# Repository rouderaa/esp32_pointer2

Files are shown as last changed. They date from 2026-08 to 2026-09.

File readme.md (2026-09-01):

# Virtual blind walking stick

This sketch turns a Benewake TFMini-S / TFMini-Plus lidar rangefinder into a parking-sensor-style audible proximity alert, streamed wirelessly to a Bluetooth A2DP speaker instead of a wired buzzer. Beep rate increases as the sensed object gets closer, and pitch steps up by an octave every 4 m of range.
The idea is that a visual impaired person can use this to navigate the environment simular to using a walking stick. The advantage of this electronic version is that the range is much larger, up to 12 metre and no toughing of the object is necessary. So for example a glass window can be measured instead of using a stick to tap it.

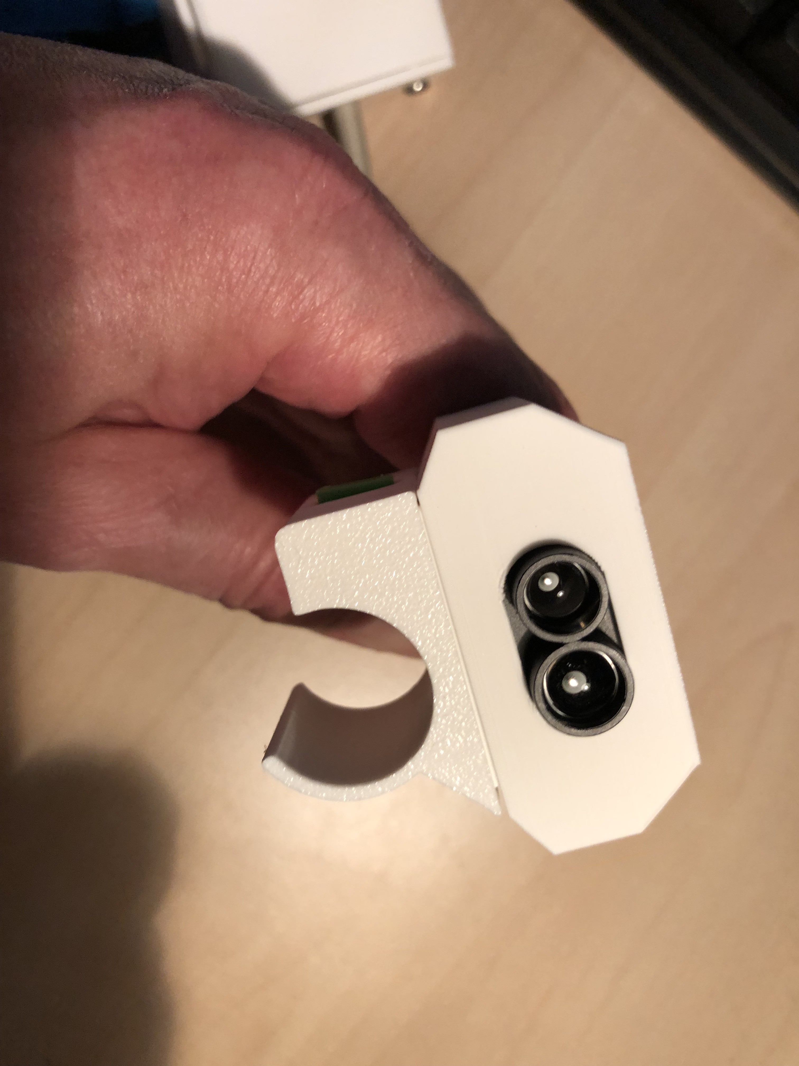
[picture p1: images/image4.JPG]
distance sensor part


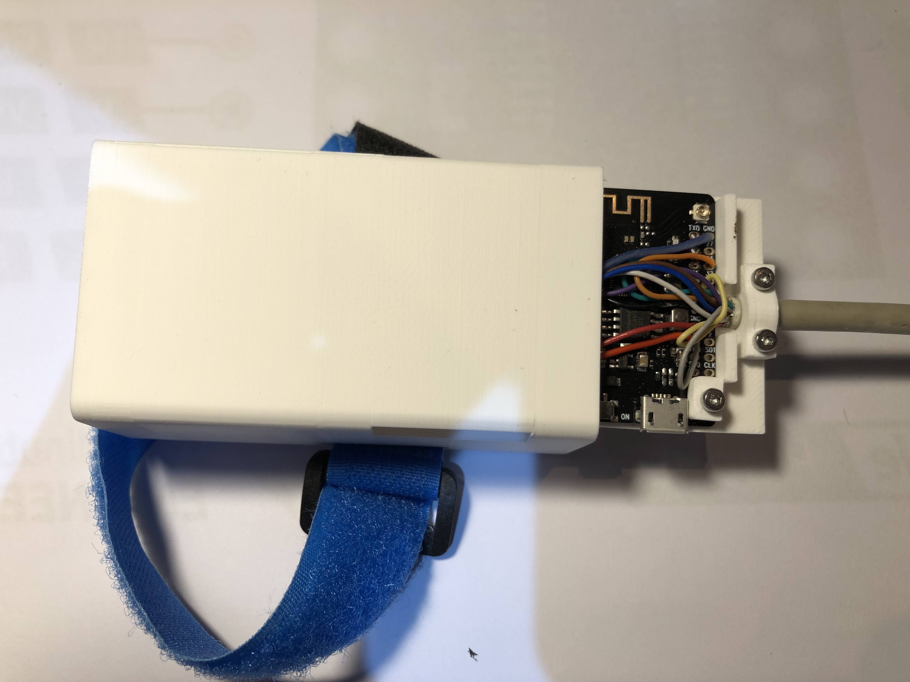
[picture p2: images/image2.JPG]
control box part


## How it works

1. **Sensing** — A TFMini-S lidar module is read over UART (ESP32 `HardwareSerial` UART1) via the `TFMPlus` driver library, reporting distance in cm at up to 100 Hz.
2. **Mapping distance → sound**
   - **Beep rate**: distance is linearly mapped from `DIST_MIN_MM`–`DIST_MAX_MM` (10 cm–12 m) to an inter-beep delay of `BEEP_DELAY_MIN_MS`–`BEEP_DELAY_MAX_MS` (80–800 ms), so closer objects beep faster.
   - **Pitch**: range is split into 4 m-wide octave bands. The farthest band plays at `BASE_FREQUENCY_HZ` (220 Hz); each band closer than that doubles the frequency, so the nearest band plays four octave-steps higher.
   - Both are recomputed continuously (non-blocking sequencer), so a sudden distance change is reflected within one `loop()` iteration (~10 ms) rather than waiting out a stale timing window.
3. **Sound synthesis** — Tones are generated in software as a small additive sine synthesis (fundamental + 4 harmonics) inside the Bluetooth audio callback (`get_sound_data`), with a short envelope ramp on beep/mute transitions to avoid audible clicks.
4. **Output** — Audio is streamed over Bluetooth A2DP (`ESP32-A2DP` library) to a paired speaker/receiver named `"B66"`, with auto-reconnect enabled.
5. **Controls**
   - A physical button (`PIN_KEY`, active-low, debounced) toggles mute; an LED (`PIN_LED`) reflects the current mute state.
   - Volume can be adjusted at runtime by sending `+` / `-` characters over the Serial console (steps of 5, clamped 0–127).

## Hardware

| Signal | ESP32 Pin | Notes |
|---|---|---|
| LED (mute indicator) | GPIO 22 | Active-high |
| Mute button | GPIO 23 | `INPUT_PULLUP`, active-low |
| Lidar RX (ESP32 RX) | GPIO 18 | TFMini-S TX → ESP32 RX |
| Lidar TX (ESP32 TX) | GPIO 21 | TFMini-S RX ← ESP32 TX |

The TFMini-S's signal pins are dual-purpose (UART RX/TX or I²C SDA/SCL). At boot, `ensureLidarUARTMode()` briefly opens the same two pins as I²C and unconditionally sends the sensor's "switch to UART mode" + "save settings" command bytes, in case a previous session left it in I²C mode. This is done unconditionally (not gated on an address probe) because a marginal I²C bus can make presence-detection unreliable. The pins are then released and reopened as UART. This step can be skipped by setting `SKIP_I2C_MODE_CHECK` to `1`.

## Configuration

Key tunables are grouped near the top of the source file:

- **Distance range**: `DIST_MIN_MM`, `DIST_MAX_MM` — sensor range mapped to sound (defaults: 10 cm–12 m, the TFMini-S's full rated range).
- **Beep timing**: `BEEP_DELAY_MIN_MS`, `BEEP_DELAY_MAX_MS`, `BEEP_ON_MS` — inter-beep gap range and fixed beep length.
- **Pitch**: `OCTAVE_BAND_MM`, `BASE_FREQUENCY_HZ` — width of each octave band and the base (farthest-band) frequency.
- **Volume**: `VOLUME_MIN`, `VOLUME_MAX`, `VOLUME_STEP` — runtime volume control bounds via Serial `+`/`-`.
- **Mute debounce**: `KEY_DEBOUNCE_MS`.
- **`DEBUG_SENSOR`** (0/1) — enables verbose Serial logging (raw sensor readings, a 1 Hz heartbeat, and a raw UART byte dump at boot). Off by default since each `Serial.printf()` costs ~1–2 ms and can add loop jitter.
- **`SKIP_I2C_MODE_CHECK`** (0/1) — skips the boot-time I²C mode-recovery step described above.

## Behavior notes

- If the sensor hasn't produced a new frame since the last `loop()` call, the last known-good distance is reused rather than treated as "out of range," so beeping stays smooth between UART frames.
- A reading is treated as invalid (and the beeper goes silent) when the TFMini-S reports a non-positive distance or a signal-strength ("flux") value below 100 — both indicate an unreliable measurement (target too close/far, low reflectivity, or ambient light saturation).
- The beep sequencer keeps running on its normal schedule even while muted; muting is applied downstream in the audio callback, so un-muting resumes in sync with the current distance instead of needing to "catch up."
- All audio-callback state (`toneState`, `muted`) is `volatile`, since it's written from `loop()` and read from the separate Bluetooth audio task.

## Dependencies

- [Arduino core for ESP32](https://github.com/espressif/arduino-esp32)
- [`TFMPlus`](https://github.com/budryerson/TFMini-Plus) — Benewake TFMini-Plus/TFMini-S UART driver
- [`ESP32-A2DP`](https://github.com/pschatzmann/ESP32-A2DP) (`BluetoothA2DPSource`)
- `Wire` (bundled with the ESP32 core)

## Usage

1. Wire the TFMini-S to the ESP32 as described above, plus the mute button and LED.
2. Install the dependencies listed above in your Arduino/PlatformIO environment.
3. Flash the sketch. On boot it will:
   - attempt to recover the lidar from I²C mode if needed,
   - verify UART communication with the sensor (halting with a Serial error if it fails),
   - set the sensor to continuous 100 Hz output,
   - start advertising/connecting as Bluetooth source `"B66"`.
4. Pair `"B66"` with your Bluetooth speaker/receiver (auto-reconnect is enabled for subsequent boots).
5. Open the Serial Monitor at 115200 baud to see status messages, and optionally send `+`/`-` to adjust volume.
6. Press the button on `PIN_KEY` to mute/unmute; the LED tracks mute state.

## Troubleshooting

- **"TFMini-S init failed — check wiring!"** at boot: the firmware-version handshake failed. Check power, and that RX/TX aren't swapped. Set `DEBUG_SENSOR` to `1` to see a raw 1-second UART byte dump at boot, which helps distinguish "nothing arriving" (power/baud/wiring) from "garbled data" (baud mismatch or swapped lines) from "sensor alive but command handshake failing."
- **No audio at all**: check the Serial log for A2DP connection-state messages (`a2dpConnectionStateChanged`) to confirm the Bluetooth link is actually established — audio silently doesn't play if it isn't. With `DEBUG_SENSOR` enabled, the 1 Hz heartbeat log also reports whether the beep sequencer is going active and whether A2DP reports connected.
- **Suspect the sensor is stuck in I²C mode**: leave `SKIP_I2C_MODE_CHECK` at `0` (default) so `ensureLidarUARTMode()` runs at boot; it will attempt to switch and save UART mode regardless of whether it can confirm the sensor's current state.# TTGO T7 v1.3 (ESP32) — PlatformIO Project

PlatformIO configuration for the **LilyGO TTGO T7 v1.3** (Mini32 / ESP32-WROVER-B), targeting Arduino framework projects that use LiDAR distance sensing (TFMini Plus) and Bluetooth A2DP audio.

## Hardware

- **Board:** LilyGO TTGO T7 v1.3 (Mini32)
- **Module:** ESP32-WROVER-B
- **PSRAM:** 4 MB
- **Flash:** 4 MB (default partition scheme, OTA-capable)

## Environment

| Setting | Value |
|---|---|
| Environment name | `ttgo-t7-v13` |
| Platform | `espressif32@6.3.2` |
| Board | `esp32dev` |
| Framework | `arduino` |

## Serial / Upload Settings

| Setting | Value |
|---|---|
| Monitor speed | `115200` |
| Monitor port | `/dev/ttyUSB2` |
| Upload speed | `921600` |
| Upload port | `/dev/ttyUSB2` |

> Adjust `monitor_port` / `upload_port` to match your system (e.g. `/dev/ttyUSB0`, `COM5`, etc.).

## Build Flags

- `-DBOARD_HAS_PSRAM` — enables the 4 MB PSRAM on the WROVER-B module
- `-mfix-esp32-psram-cache-issue` — required compiler workaround for ESP32 PSRAM cache bug
- `-DARDUINO_ESP32_DEV` — identifies the board variant to the Arduino core
- `-DARDUINO_USB_CDC_ON_BOOT=0` — disables USB CDC on boot to avoid an undefined-reference error on `Serial1`

## Partition Scheme

Uses the `default.csv` partition table (4 MB flash) with OTA update support.

## Optional Settings

The following are commented out in `platformio.ini` and can be enabled if needed (e.g. for PSRAM-heavy tasks or custom flash configurations):

```ini
; board_build.f_cpu = 240000000L
; board_build.f_flash = 80000000L
; board_build.flash_mode = dio
```

## Library Dependencies

| Library | Purpose |
|---|---|
| [`budryerson/TFMPlus`](https://github.com/budryerson/TFMPlus) | Driver for the TFMini Plus LiDAR distance sensor |
| [`ESP32-A2DP`](https://github.com/pschatzmann/ESP32-A2DP) | Bluetooth A2DP audio source/sink for ESP32 |
| [`arduino-audio-tools`](https://github.com/pschatzmann/arduino-audio-tools) | Audio processing utilities for Arduino/ESP32 |

## Getting Started

1. Install [PlatformIO](https://platformio.org/) (VS Code extension or CLI).
2. Clone this repository and open it in PlatformIO.
3. Connect the TTGO T7 v1.3 board via USB and confirm the serial port matches `upload_port` / `monitor_port`.
4. Build and upload:
   ```bash
   pio run -e ttgo-t7-v13 -t upload
   ```
5. Open the serial monitor:
   ```bash
   pio device monitor -e ttgo-t7-v13
   ```

## Notes

- If you encounter an undefined reference to `Serial1`, confirm `ARDUINO_USB_CDC_ON_BOOT=0` is set (already included above).
- PSRAM must remain enabled (`BOARD_HAS_PSRAM`) for any PSRAM-heavy audio or buffering tasks.

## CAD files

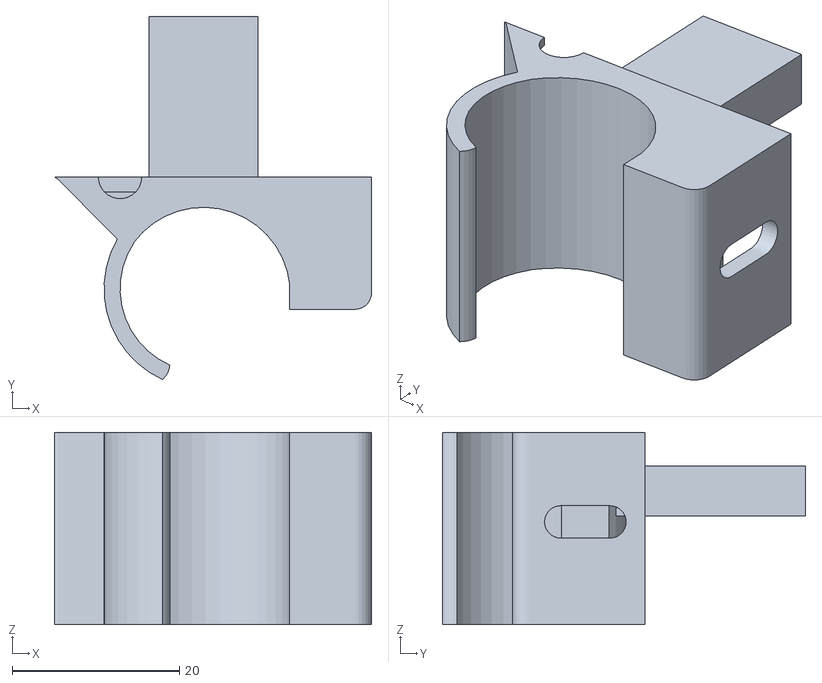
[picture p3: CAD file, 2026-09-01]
design/pointer2-bottom001.stl
38.0 x 43.5 x 23.0

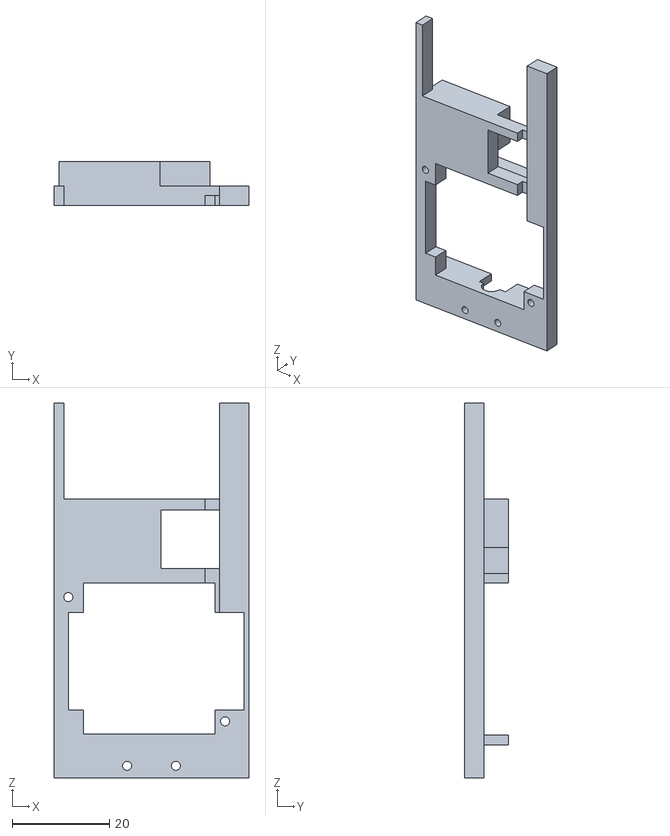
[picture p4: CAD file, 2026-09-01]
design/pointer2-frame004.stl
40.0 x 9.00 x 77.0

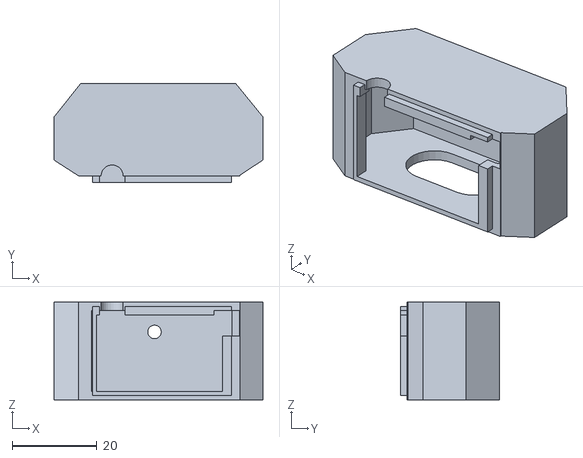
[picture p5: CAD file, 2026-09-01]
design/pointer2-topPart004.stl
49.3 x 23.2 x 23.0

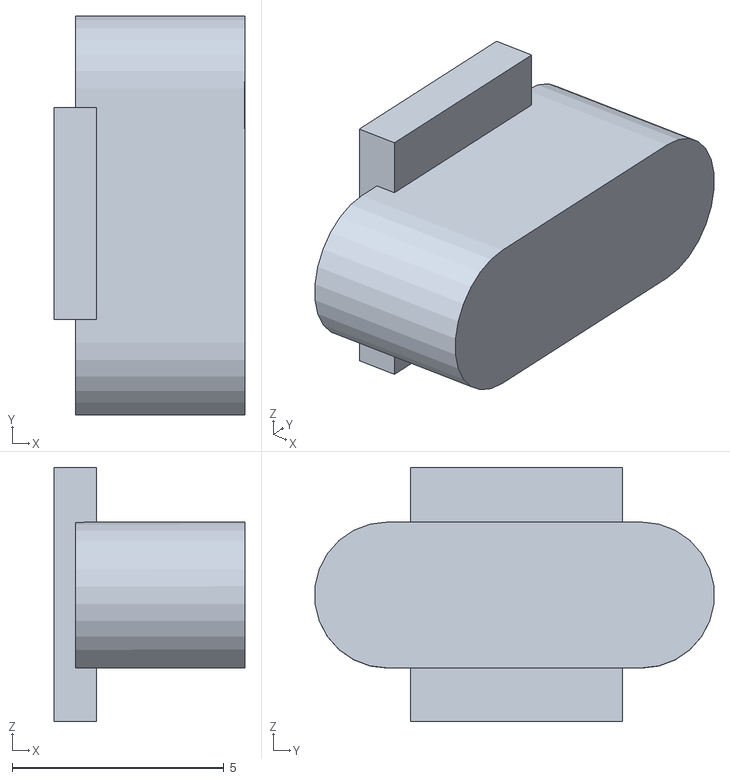
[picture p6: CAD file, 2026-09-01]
design/pointer2-buttonCap001.stl
4.51 x 9.42 x 6.00

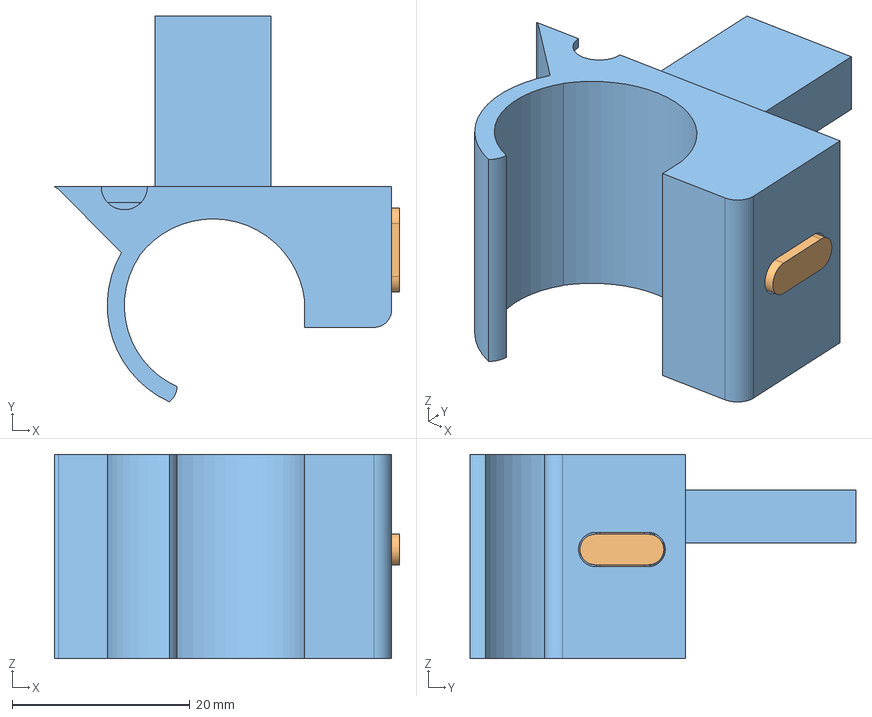
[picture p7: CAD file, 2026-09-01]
design/pointer2.FCStd
38.9 x 43.5 x 23.0 mm
tactbutton002
buttonCap001
bottom001

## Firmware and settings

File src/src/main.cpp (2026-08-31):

#define LOG_LOCAL_LEVEL ESP_LOG_DEBUG

#include <Arduino.h>
#include <Wire.h>    // only used briefly at boot, see ensureLidarUARTMode()
#include <TFMPlus.h> // Benewake TFMini-Plus/TFMini-S driver, UART mode
#include "BluetoothA2DPSource.h"

// ── Sensor mode auto-configuration ───────────────────────────────────────────
// The TFMini-S's two signal pins are dual-purpose: RX/TX in UART mode,
// SDA/SCL in I2C mode. If an earlier test left the sensor switched into I2C
// mode, ensureLidarUARTMode() (called once at boot, before the UART is
// opened) detects that over I2C and switches it back — no rewiring needed.

// ── Pin definitions ──────────────────────────────────────────────────────────
#define PIN_LED 22
#define PIN_KEY 23
#define PIN_LIDAR_RX 18 // ESP32 RX <- TFMini-S TX (== SDA in I2C mode)
#define PIN_LIDAR_TX 21 // ESP32 TX -> TFMini-S RX (== SCL in I2C mode)

// I2C address the sensor would be using if still in I2C mode from an
// earlier test — only used by ensureLidarUARTMode() below.
#define LIDAR_I2C_ADDR 0x10

// ── Distance / beep configuration ────────────────────────────────────────────
// The TFMini-S reports in cm; we convert to mm and work in mm throughout.
// 12 m is the sensor's full rated range.
const uint16_t DIST_MIN_MM = 100;   //  10 cm — closest expected
const uint16_t DIST_MAX_MM = 12000; // 1200 cm — furthest expected (sensor's full range)

// Inter-beep delay: short distance → short delay (rapid beeps)
const uint32_t BEEP_DELAY_MIN_MS = 80;  // ms at closest distance
const uint32_t BEEP_DELAY_MAX_MS = 800; // ms at furthest distance

// How long each beep toneState lasts (fixed)
const uint32_t BEEP_ON_MS = 60;

// ── Pitch configuration ───────────────────────────────────────────────────────
// The beep's pitch steps up a full octave for every 4 m *closer* the object
// is, on top of the continuous distance→rate mapping above. The farthest
// band (8-12 m) plays at BASE_FREQUENCY_HZ, each band closer than that
// doubles the frequency, so the nearest band (0-4 m) plays loudest/highest
// at 4x BASE_FREQUENCY_HZ. Swap back to an ascending mapping (drop the
// inversion in updateBeepSequencer()) if you'd rather have farther objects
// sound higher again.
const uint32_t OCTAVE_BAND_MM = 4000;   // every 4 m = one octave step
const float BASE_FREQUENCY_HZ = 220.0f; // pitch for the farthest band
const uint8_t OCTAVE_BAND_COUNT = (DIST_MAX_MM + OCTAVE_BAND_MM - 1) / OCTAVE_BAND_MM; // ceil

// ── Debug printing toggle ─────────────────────────────────────────────────────
// Serial.printf() at 115200 baud is not free — each call costs roughly 1-2 ms.
// That's negligible on its own, but turn this off once you're done tuning so it
// can't add jitter to the loop timing.
#define DEBUG_SENSOR 0

// Set to 1 to skip ensureLidarUARTMode() entirely — useful for isolating
// whether that boot-time I2C probe/switch step is itself part of a problem,
// now that the physical wiring has been confirmed good with a multimeter.
#define SKIP_I2C_MODE_CHECK 0

// ── Volume control configuration ─────────────────────────────────────────────
// Read from Serial: '+' increases volume, '-' decreases volume.
// BluetoothA2DPSource::set_volume() takes a uint8_t in the range 0-127.
const uint8_t VOLUME_MIN = 0;
const uint8_t VOLUME_MAX = 127;
const uint8_t VOLUME_STEP = 5;

// ── Mute button configuration ────────────────────────────────────────────────
// PIN_KEY is wired active-low (INPUT_PULLUP: idle HIGH, pressed reads LOW).
// A single press toggles mute; the LED reflects the current mute state
// rather than the raw, momentary button state.
const uint32_t KEY_DEBOUNCE_MS = 50;

// ── Global objects ────────────────────────────────────────────────────────────
BluetoothA2DPSource a2dp_source;
HardwareSerial lidarSerial(1); // ESP32 UART1, dedicated to the TFMini-S
TFMPlus tfmP;

// ── Global toneState state (written from loop, read from audio ISR-like callback) ──
struct ToneState
{
  volatile bool active;
  volatile float amplitude;
  volatile float frequency;
};

static ToneState toneState = {
    .active = false,
    .amplitude = 8000.0,
    .frequency = BASE_FREQUENCY_HZ};

// Mute flag — read by the audio callback (get_sound_data), written by
// updateMuteButton() in loop(). volatile for the same reason as toneState:
// it's shared across the loop() context and the Bluetooth audio task.
static volatile bool muted = false;

// ── Beep sequencer state ──────────────────────────────────────────────────────
// phaseStartMs marks when the current ON or OFF phase began. Unlike a fixed
// "next event" timestamp, we recompute the phase's *duration* from the latest
// beepIntervalMs on every single call — so if the measured distance suddenly
// changes mid-phase, the very next loop() iteration (≈10 ms later) reacts to
// it instead of waiting for the old, stale phase to finish.
static uint32_t phaseStartMs = 0;
static bool beepCurrentlyOn = false;
static uint32_t beepIntervalMs = BEEP_DELAY_MAX_MS;

// ── Distance-reading cache ────────────────────────────────────────────────────
// readDistanceMm() only gets a *new* sample when a complete frame has arrived
// over UART, but loop() runs far more often. We need to tell the difference
// between "no new frame yet" (keep using last good value) and "sensor
// reported an invalid/out-of-range reading" (actually go silent).
static uint16_t lastValidDistMm = 0;
static bool haveValidReading = false;

// ── Volume state ──────────────────────────────────────────────────────────────
static uint8_t currentVolume = 40; // matches the initial a2dp_source.set_volume(40) below

// ── float map helper (Arduino map() is integer-only) ─────────────────────────
float mapf(float x, float in_min, float in_max, float out_min, float out_max)
{
  return (x - in_min) * (out_max - out_min) / (in_max - in_min) + out_min;
}

// ─────────────────────────────────────────────────────────────────────────────
// TFMini-S I2C→UART mode switch — call once, before opening the UART.
//
// If a previous test left the sensor in I2C mode, it will answer at
// LIDAR_I2C_ADDR on the I2C bus. If it does, we send it the raw command
// bytes (from Benewake's TFMini-S protocol) to switch back to UART and save
// that setting:
//   - Set communication mode to UART: 5A 05 0A 00 69
//   - Save settings (required on the TFMini-S for the mode change to stick):
//     5A 04 11 6F
// If nothing answers on I2C, we assume the sensor is already in UART mode
// (its native, default state) and leave it alone. Either way, the I2C bus
// is released afterwards so the same pins are free to be reopened as UART.
//
// Returns true if an I2C-mode sensor was found and switched.
// ─────────────────────────────────────────────────────────────────────────────
bool ensureLidarUARTMode()
{
  Wire.begin(PIN_LIDAR_RX, PIN_LIDAR_TX);
  Wire.setClock(100000);
  delay(50);

  // Send the switch-to-UART + save-settings commands over I2C
  // unconditionally, rather than gating on an address probe first. A
  // marginal/under-pulled-up I2C bus can make that probe unreliable (it can
  // report "not found" even when the sensor is there), which would leave a
  // still-I2C-mode sensor stuck that way. If the sensor is actually already
  // in UART mode, these bytes are just meaningless noise on lines it's no
  // longer treating as I2C — harmless either way.
  Serial.println("TFMini-S: ensuring UART mode (sending switch-back over I2C)...");

  const uint8_t setSerialModeCmd[] = {0x5A, 0x05, 0x0A, 0x00, 0x69};
  Wire.beginTransmission(LIDAR_I2C_ADDR);
  Wire.write(setSerialModeCmd, sizeof(setSerialModeCmd));
  Wire.endTransmission();
  delay(50);

  const uint8_t saveSettingsCmd[] = {0x5A, 0x04, 0x11, 0x6F};
  Wire.beginTransmission(LIDAR_I2C_ADDR);
  Wire.write(saveSettingsCmd, sizeof(saveSettingsCmd));
  Wire.endTransmission();
  delay(300); // give the sensor time to apply the change

  Wire.end();

  // Explicitly release these pins from the I2C peripheral's grip before the
  // UART opens them — on some ESP32 core versions Wire.end() doesn't fully
  // detach the GPIO-matrix routing, which can leave I2C fighting the UART
  // peripheral for control of the same two wires right after.
  pinMode(PIN_LIDAR_RX, INPUT);
  pinMode(PIN_LIDAR_TX, INPUT);
  delay(50);

  return true;
}

// ─────────────────────────────────────────────────────────────────────────────
// A2DP connection-state logging — lets us see on Serial whether the
// Bluetooth link to the speaker is actually being made at all, since no
// audio ever plays if it isn't (silently, with no other symptom).
// ─────────────────────────────────────────────────────────────────────────────
void a2dpConnectionStateChanged(esp_a2d_connection_state_t state, void *)
{
  const char *stateNames[] = {"DISCONNECTED", "CONNECTING", "CONNECTED", "DISCONNECTING"};
  Serial.printf("A2DP connection state: %s\n", stateNames[state]);
}

// ─────────────────────────────────────────────────────────────────────────────
// Audio callback — runs on the Bluetooth task; reads volatile toneState state only.
// ─────────────────────────────────────────────────────────────────────────────
int32_t get_sound_data(Frame *data, int32_t frame_count)
{
  static float phase = 0.0f;
  static float envelope = 0.0f; // 0..1, ramps toward toneState.active
  const float sampleRate = 44100.0f;

  // Time (in samples) for the envelope to ramp fully between silent and
  // full volume. An instant on/off jump is a step discontinuity, which a
  // speaker reproduces as an audible click/crack. A few milliseconds is
  // short enough to stay snappy against the ~60 ms beep length, but long
  // enough that the transition is inaudible as a click.
  const float ENVELOPE_RAMP_MS = 3.0f;
  const float envelopeStep = 1.0f / (ENVELOPE_RAMP_MS * 0.001f * sampleRate);

  for (int i = 0; i < frame_count; i++)
  {
    // Muting is folded in here (rather than in the sequencer) so the same
    // envelope ramp that avoids clicks on normal beep on/off also covers
    // mute on/off — no separate fade logic needed, and a mute toggled
    // mid-beep still ends cleanly instead of cutting off abruptly.
    float target = (toneState.active && !muted) ? 1.0f : 0.0f;
    if (envelope < target)
    {
      envelope += envelopeStep;
      if (envelope > target)
        envelope = target;
    }
    else if (envelope > target)
    {
      envelope -= envelopeStep;
      if (envelope < target)
        envelope = target;
    }

    int16_t sample = 0;
    if (envelope > 0.0f)
    {
      float a = toneState.amplitude * envelope;
      float f = toneState.frequency;
      sample = (int16_t)(a * 0.5161f * sinf(phase) +
                         a * 0.2581f * sinf(2.0f * phase) +
                         a * 0.1290f * sinf(4.0f * phase) +
                         a * 0.0645f * sinf(6.0f * phase) +
                         a * 0.0323f * sinf(8.0f * phase));
    }
    data[i].channel1 = sample;
    data[i].channel2 = sample;

    // Phase advances continuously (even while silent) so there's no phase
    // discontinuity if a new beep starts before the envelope has fully
    // settled — only the envelope gates the audible amplitude.
    phase += 2.0f * PI * toneState.frequency / sampleRate;
    if (phase > 2.0f * PI)
      phase -= 2.0f * PI;
  }
  return frame_count;
}

// ─────────────────────────────────────────────────────────────────────────────
// Mute button — call every loop iteration.
// Debounces PIN_KEY (active-low) and toggles `muted` on each press
// (HIGH -> LOW transition), so one press mutes and the next press unmutes.
// ─────────────────────────────────────────────────────────────────────────────
void updateMuteButton()
{
  static bool lastRawKeyState = HIGH;
  static bool debouncedKeyState = HIGH;
  static uint32_t lastKeyChangeMs = 0;

  uint32_t now = millis();
  bool rawKeyState = digitalRead(PIN_KEY);

  if (rawKeyState != lastRawKeyState)
  {
    lastKeyChangeMs = now;
    lastRawKeyState = rawKeyState;
  }

  if ((now - lastKeyChangeMs) >= KEY_DEBOUNCE_MS && rawKeyState != debouncedKeyState)
  {
    debouncedKeyState = rawKeyState;

    // Toggle only on the press edge (idle HIGH -> pressed LOW), not on release,
    // so holding the key down doesn't re-toggle anything.
    if (debouncedKeyState == LOW)
    {
      muted = !muted;
      Serial.printf("Mute: %s\n", muted ? "ON" : "OFF");
    }
  }
}

// ─────────────────────────────────────────────────────────────────────────────
// LED — reflects current mute state (on = muted), independent of whether
// the key is currently being held.
// ─────────────────────────────────────────────────────────────────────────────
void updateMuteLed()
{
  digitalWrite(PIN_LED, muted ? HIGH : LOW);
}

// ─────────────────────────────────────────────────────────────────────────────
// Volume control — call every loop iteration.
// Reads '+'/'-' characters from Serial and adjusts a2dp_source volume,
// clamped to [VOLUME_MIN, VOLUME_MAX]. Prints the new volume on change.
// ─────────────────────────────────────────────────────────────────────────────
void updateVolumeControl()
{
  while (Serial.available() > 0)
  {
    char c = Serial.read();
    bool changed = false;

    if (c == '+')
    {
      uint8_t newVolume = (currentVolume > VOLUME_MAX - VOLUME_STEP)
                              ? VOLUME_MAX
                              : currentVolume + VOLUME_STEP;
      changed = (newVolume != currentVolume);
      currentVolume = newVolume;
    }
    else if (c == '-')
    {
      uint8_t newVolume = (currentVolume < VOLUME_MIN + VOLUME_STEP)
                              ? VOLUME_MIN
                              : currentVolume - VOLUME_STEP;
      changed = (newVolume != currentVolume);
      currentVolume = newVolume;
    }
    else
    {
      // Ignore any other character (newlines, other input, etc.)
      continue;
    }

    if (changed)
    {
      a2dp_source.set_volume(currentVolume);
      // Serial.printf("Volume: %u\n", currentVolume);
    }
  }
}

// ─────────────────────────────────────────────────────────────────────────────
// TFMini-S — read latest ranging result (mm).
//
// Returns:
//   - the last known-good distance if no complete frame is ready yet
//     (tfmP.getData() returns false) — this is NOT the same as "out of range"
//   - 0 if the sensor explicitly reports an invalid/unreliable reading
//   - the freshly read distance otherwise
// ─────────────────────────────────────────────────────────────────────────────
uint16_t readDistanceMm()
{
  int16_t tfDist = 0; // cm
  int16_t tfFlux = 0; // signal strength
  int16_t tfTemp = 0; // chip temperature

  if (!tfmP.getData(tfDist, tfFlux, tfTemp))
  {
    // No new complete frame parsed this call — reuse the last valid reading
    // so the beep sequencer keeps running smoothly between sensor updates.
    return haveValidReading ? lastValidDistMm : 0;
  }

#if DEBUG_SENSOR
  Serial.printf("Range: %d cm | Flux: %d | Temp: %d | Volume: %u\n",
                tfDist, tfFlux, tfTemp, currentVolume);
#endif

  // TFMini-S reports a non-positive distance, or a low signal-strength
  // (flux) value, when the reading is unreliable — target too close, too
  // far, low-reflectivity, or ambient light saturation.
  if (tfDist <= 0 || tfFlux < 100)
  {
    haveValidReading = false;
    return 0;
  }

  haveValidReading = true;
  lastValidDistMm = (uint16_t)(tfDist * 10); // cm -> mm
  return lastValidDistMm;
}

// ─────────────────────────────────────────────────────────────────────────────
// Beep sequencer — call every loop iteration.
// Updates toneState.active/frequency based on a non-blocking ON/OFF schedule
// derived from the measured distance: shorter distance → shorter inter-beep
// interval, and every 4 m of distance steps the pitch up one octave.
//
// The OFF-phase gap is recomputed from the *current* beepIntervalMs on every
// call (relative to when the phase started), instead of being locked in once
// when the phase began. That means a sudden distance change takes effect
// within one loop() iteration (~10 ms) instead of waiting for the previously
// scheduled, now-stale gap to finish.
//
// Note: this keeps scheduling beeps on its normal timing even while muted —
// muting is applied downstream, in the audio callback — so the moment mute
// is turned off, beeping resumes in sync with distance rather than needing
// to "catch up".
// ─────────────────────────────────────────────────────────────────────────────
void updateBeepSequencer(uint16_t distMm)
{
  uint32_t now = millis();

  // ── Update the interval and pitch from the latest distance reading ────────
  if (distMm >= DIST_MIN_MM && distMm <= DIST_MAX_MM)
  {
    beepIntervalMs = (uint32_t)mapf(
        (float)distMm,
        (float)DIST_MIN_MM, (float)DIST_MAX_MM,
        (float)BEEP_DELAY_MIN_MS, (float)BEEP_DELAY_MAX_MS);

    uint32_t band = distMm / OCTAVE_BAND_MM;
    if (band >= OCTAVE_BAND_COUNT)
      band = OCTAVE_BAND_COUNT - 1;
    uint32_t invertedBand = (OCTAVE_BAND_COUNT - 1) - band; // close = high pitch, far = low pitch
    toneState.frequency = BASE_FREQUENCY_HZ * (float)(1UL << invertedBand); // x2 per 4 m band
  }
  else
  {
    // Genuinely out of range (or no valid reading has ever been seen): silence.
    // distMm == 0 only reaches here when readDistanceMm() explicitly reported
    // an invalid status, not merely because a new sample wasn't ready yet.
    if (toneState.active || beepCurrentlyOn)
    {
      toneState.active = false;
      beepCurrentlyOn = false;
      phaseStartMs = now;
    }
    return;
  }

  // ── Non-blocking sequencer, re-evaluated live against beepIntervalMs ──────
  uint32_t elapsed = now - phaseStartMs;

  if (!beepCurrentlyOn)
  {
    // Waiting out the silent gap. Gap length is derived fresh each call, so
    // it shrinks/grows immediately as the distance (and thus interval) changes.
    uint32_t gapMs = (beepIntervalMs > BEEP_ON_MS)
                         ? (beepIntervalMs - BEEP_ON_MS)
                         : 0;
    if (elapsed >= gapMs)
    {
      toneState.active = true;
      beepCurrentlyOn = true;
      phaseStartMs = now;
    }
  }
  else
  {
    // Beep is sounding — fixed short ON duration, no need to react here.
    if (elapsed >= BEEP_ON_MS)
    {
      toneState.active = false;
      beepCurrentlyOn = false;
      phaseStartMs = now;
    }
  }
}

// ─────────────────────────────────────────────────────────────────────────────
// setup
// ─────────────────────────────────────────────────────────────────────────────
void setup()
{
  Serial.begin(115200);

  // ── GPIO ──────────────────────────────────────────────────────────────────
  pinMode(PIN_LED, OUTPUT);
  digitalWrite(PIN_LED, LOW);
  pinMode(PIN_KEY, INPUT_PULLUP);

  // ── TFMini-S startup sequence (UART) ────────────────────────────────────
  // Make sure the sensor isn't still left in I2C mode from an earlier test.
#if !SKIP_I2C_MODE_CHECK
  ensureLidarUARTMode();
#endif

  lidarSerial.begin(115200, SERIAL_8N1, PIN_LIDAR_RX, PIN_LIDAR_TX);
  delay(100);
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
void loop()
{
  // ── Key → mute toggle, LED reflects mute state ───────────────────────────
  updateMuteButton();
  updateMuteLed();

  // ── Volume control via Serial ('+' / '-') ───────────────────────────────────
  updateVolumeControl();

  // ── Read TFMini-S ─────────────────────────────────────────────────────────
  uint16_t distMm = readDistanceMm();

  // if (distMm > 0) {
  //   Serial.printf("Distance: %u mm\n", distMm);
  // }

  // ── Drive beep sequencer from measured distance ────────────────────────────
  updateBeepSequencer(distMm);

#if DEBUG_SENSOR
  // Throttled heartbeat: confirms whether the beep sequencer is actually
  // going active, independent of whatever the TFMini-S debug line above
  // says — if this never shows active=1, no tone is ever being sent to the
  // A2DP callback regardless of whether Bluetooth is connected.
  static uint32_t lastHeartbeatMs = 0;
  uint32_t nowMs = millis();
  if (nowMs - lastHeartbeatMs >= 1000)
  {
    lastHeartbeatMs = nowMs;
    Serial.printf("Heartbeat: dist=%u mm | active=%d | freq=%.0f Hz | a2dp_connected=%d | muted=%d\n",
                  distMm, toneState.active, toneState.frequency, a2dp_source.is_connected(), muted);
  }
#endif

  // Short sleep — keeps the loop responsive without busy-spinning.
  // The beep sequencer is non-blocking so this does not affect timing accuracy.
  delay(10);
}
